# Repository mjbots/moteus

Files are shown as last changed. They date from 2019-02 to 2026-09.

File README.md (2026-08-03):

# moteus brushless servo #

This contains full designs for the moteus brushless servo actuator,
including firmware and PCBs.

**WARNING**: This is not just a software project.  It includes designs
for moderately high power electronics.  It has not yet burned down my
(or anyone's that I know of) house, but there are no guarantees.

# Specifications #

| Name | r4.11 | c1 | n1 | x1 |
|---|---|---|---|---|
| Voltage Input | 10-44V | 10-51V | 10-54V | 10-54V |
| Peak Electrical Power  | 900W @ 30V | 250W @ 28V | 1.3kW @ 36V | 1kW @ 36V |
| Mass | 14.2g | 8.9g | 14.6g | 23.8g |
| Control Rate | 15-30kHz | - | - | - |
| PWM Switching Rate | 15-60kHz | - | - | - |
| CPU | STM32G4 | - | - | - |
| Uncooled phase current | 12A | 5A | 9A | 25A |
| Cooled phase current | 32A | 14A | 26A | 62A |
| Peak phase current | 100A | 20A | 100A | 120A |
| Communications | 5Mbps CAN-FD | - | - | - |
| Dimensions | 46x53mm | 38x38x9mm  | 46x46x8mm | 56x56x10mm  |

Assembled and tested boards can be purchased at: https://mjbots.com

# Directory structure #

* hw/ - hardware (mechanical and electrical designs)
  * controller/ - PCB design for moteus-r4.11
  * c1/ - PCB design for moteus-c1
  * n1/ - PCB design for moteus-n1
  * x1/ - PCB design for moteus-x1
* fw/ - firmware for brushless controller
* lib/ - client side software
* utils/ - diagnostic tools
* tools/ - bazel build configure
* docs/ - documentation

# Documentation #

* [Quick Start](https://mjbots.github.io/moteus/quick-start)
* [All Documentation](https://mjbots.github.io/moteus/)
* [Discord](https://discord.gg/W4hUpBb)

# Misc #

 * 

# How to support moteus development #

The easiest way to support development the moteus hardware and firmware is as follows:

1) Buy things from https://mjbots.com
2) Build awesome machines!

That's it!  If for some reason you want to go above and beyond, you can sponsor mjbots through github: https://github.com/sponsors/mjbots

# License #

All files contained in this repository, unless otherwise noted, are
available under an Apache 2.0 License:
https://www.apache.org/licenses/LICENSE-2.0

# Trademark #

mjbots Robotic Systems LLC owns and protects the "mjbots" and "moteus" trademarks in many jurisdictions.

If you want to use these names in your project or product, please read the [Trademark Policy](https://mjbots.com/trademark-policy)

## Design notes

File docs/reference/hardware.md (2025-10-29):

# Hardware Specifications

## CAD and Models

| Name | 2D CAD | 3D Model |
|---|---|---|
| moteus-c1 |[2D CAD](https://github.com/mjbots/moteus/blob/0.1-20240430/hw/c1/r1.2/20240305-moteus-c1-r1_2.pdf) | [STEP](https://github.com/mjbots/moteus/blob/0.1-20240430/hw/c1/r1.2/20240305-moteus-c1-r1_2.step) |
| moteus-r4 |[2D CAD](https://github.com/mjbots/moteus/blob/main/hw/controller/r4.5/20210124-moteus-controller-r45-mechanical.pdf) | [STEP](https://github.com/mjbots/moteus/blob/main/hw/controller/r4.5/20210124-moteus-controller-r45-mechanical.step) |
| moteus-x1 | [2D CAD](https://drive.google.com/file/d/1R7wuc7vk1khD5ZvDWPy54Bx4PgHYiUCu/view) | [STEP](https://drive.google.com/file/d/19tJa4gzy0ZBWYYsaJA-Du0PgzoDWizjL/view?usp=sharing) |
| moteus-n1 | [2D CAD](https://drive.google.com/file/d/1Ic65vT8BSeTtqz6uqd8C7l68aOMy3bMz/view?usp=share_link) | [STEP](https://drive.google.com/file/d/1wxX5G6kX6M6YZGGSceiXTOUZycxRaSIE/view?usp=share_link) |

## Electrical Limits

| Name | Min Voltage | Nominal | Abs Max Voltage | Peak Output | 3V Aux |  5V Aux | 12V Aux |
|---|---|---|---|---|---|---|---|
| moteus-c1 | 10V | 24V | 51V (<= 12S) | 20A | 50mA | 100mA | N/A |
| moteus-r4 | 10V | 24V | 44V (<= 10S) | 100A | 100mA | N/A | N/A |
| moteus-x1 | 10V | 24V | 54V (<= 12S) | 120A | 100mA | 200mA | 150mA |
| moteus-n1 | 10V | 24V | 54V (<= 12S) | 100A | 100mA | 200mA | N/A |

## Power Limits

The allowable maximum power for each moteus controller depends upon
the input voltage and PWM switching frequency.  The below table gives
the maximum allowable power at `servo.pwm_rate_hz=30000`.

| Name | Peak power | | High input power |
|---|---|---|---|
| moteus-r4  | <= 30V 900W  | linear derated | >= 38V 400W |
| moteus-c1  | <= 28V 250W  | linear derated | >= 41V 150W |
| moteus-n1  | <= 36V 2000W | linear derated | >= 44V 1000W |

For other values of `servo.pwm_rate_hz`, the allowable maximum power
changes linearly with the PWM rate, so that at 15000, the maximum
power is half of that in the above table and at 60000 it is double
that.  Note however, that efficiency of the controller goes down
significantly at higher PWM rates.

The current power limit is reported in `servo_stats.max_power_W`.  The
controller will attempt to limit output phase current so as to stay
within this reported power limit in either direction, i.e. applying
power or regenerating energy.

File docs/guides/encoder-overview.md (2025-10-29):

# Encoder Overview

This section describes the various ways moteus can be configured to use encoders to sense the rotor, output, or auxiliary devices.  If you intend to only use the onboard on-axis magnetic encoder, you can skip this section.

## Introduction

moteus uses encoders to properly control a motor. Encoders provide the feedback needed to know where the motor is and how fast it's moving. Understanding which encoder(s) to use and how to configure them is one of the key decisions you need to make when designing a system, as for many applications encoder selection is the primary determinant of performance parameters like maximum stiffness, control stability and whether homing will be necessary.

Moteus uses encoders for two distinct purposes. First, it needs **commutation** feedback - the electrical relationship between the motor's stator and rotor to apply torque correctly. Second, it needs **output** feedback - the position and velocity of your output shaft to follow commanded trajectories. A single encoder can serve both purposes, or you can use separate encoders for each.

The good news is that moteus comes with an onboard AS5047P or MA600 magnetic encoder that works out of the box for many applications. This encoder mounts on-axis with the motor. For many use cases, especially those without gear reductions, this is all you need. However, if you're using hall sensors, need higher resolution, or have a gear reducer that you want to measure the output of a reducer or other auxiliary devices, you'll want to add other encoders.

In this guide, we'll cover a few common variants and leave the rest for [the detailed encoder reference](../reference/encoders.md).

## Common Configurations

Here are the most common encoder configurations you'll encounter:

**Default configuration (onboard encoder only):** The AS5047P or MA600 onboard encoder serves as both commutation and output sensor. This works well for many applications, especially those without a reducer installed or with a reducer where either the absolute position of the output is not required or a homing step is permitted.

**Adding hall sensors:** Hall effect sensors provide robust commutation feedback and are useful in high-vibration environments or when cost is a primary concern.  When used as the only encoder, the resulting system will have poor low-velocity and position tracking performance.

**Dual encoder setups:** Using one encoder for commutation (typically the onboard or hall sensors) and a separate high-resolution encoder for output position provides the best performance for precision applications.

These two options are described in separate guides below:

- [Motor with Hall Effects](hall-effects.md) - Adding hall sensors for commutation
- [Dual Encoders](dual-encoders.md) - Using separate encoders for commutation and output

Once again, for detailed information about encoder configuration parameters, see the [Detailed Encoder Reference](../reference/encoders.md).

## Next Steps

Once the encoder has been configured, then you are ready to move on to the [motor calibration procedure](calibration.md).

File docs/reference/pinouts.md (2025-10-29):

# Pinouts

## moteus-c1



## moteus-r4



## moteus-x1



## moteus-n1



## Additional Information

### CAN Termination

CAN connections should be terminated by a 120 ohm resistor at both
ends of a bus.  Some mjbots products have built in termination
resistors, such as the pi3hat.  The mjcanfd-usb-1x and fdcanusb have a
software configurable termination resistor that is by default on.
moteus controllers have no termination resistors.  For very short
runs, the system will work terminated only on one side.  However, when
runs become longer than 0.5m, you will likely need to terminate both
ends.  This can be done by crimping a 120 ohm resistor into a JST PH3
connector and connecting it to the open data connector or by
purchasing a [CAN terminator](https://mjbots.com/products/jst-ph3-can-fd-terminator).

### Recommended Mating Hardware

| Connector | Mate P/N | Terminal P/N | Pre-crimped Wire |
|---|---|---|---|
| JST PH-3  | [PHR-3](https://mjbots.com/products/phr-3)  | [SPH-002T-P0.5L](https://mjbots.com/products/jst-ph-terminal) | [10cm, 30cm, 50cm PH3](https://mjbots.com/products/jst-ph3-cable) |
| JST GH-6  | [GHR-06V-S](https://mjbots.com/products/jst-gh6-housing) | [SSHL-002T-P0.2](https://www.digikey.com/en/products/detail/jst-sales-america-inc/SSHL-002T-P0-2/807828) | [28 AWG 20cm](https://mjbots.com/products/jst-gh-wire) |
| JST GH-7  | [GHR-07V-S](https://mjbots.com/products/jst-gh7-housing) | [SSHL-002T-P0.2](https://www.digikey.com/en/products/detail/jst-sales-america-inc/SSHL-002T-P0-2/807828) | [28 AWG 20cm](https://mjbots.com/products/jst-gh-wire) |
| JST GH-8  | [GHR-08V-S](https://mjbots.com/products/jst-gh8-housing) | [SSHL-002T-P0.2](https://www.digikey.com/en/products/detail/jst-sales-america-inc/SSHL-002T-P0-2/807828) | [28 AWG 20cm](https://mjbots.com/products/jst-gh-wire) |
| JST ZH-4  | [ZHR-4](https://www.digikey.com/en/products/detail/jst-sales-america-inc/ZHR-4/608643) | [SZH-002T-P0.5](https://www.digikey.com/en/products/detail/jst-sales-america-inc/SZH-002T-P0-5/527363) | |
| JST ZH-6  | [ZHR-6](https://www.digikey.com/en/products/detail/jst-sales-america-inc/ZHR-6/527361) | [SZH-002T-P0.5](https://www.digikey.com/en/products/detail/jst-sales-america-inc/SZH-002T-P0-5/527363) | [stm32 programmer](https://mjbots.com/products/stm32-programmer) |
| AMass XT30 | [XT30U-F](https://mjbots.com/products/xt30u-f) | | |

### Recommended Low Cost Manual Crimp Tools

- **JST PH**: [TU-190-08](https://www.amazon.com/TU-190-08-Terminals-Tool-Crimping-0-08-0-5sq-mm/dp/B01M25OLZY)
- **JST ZH**: [PEBA 1020M](https://www.amazon.com/PEBA-Ratcheting-Connectors-Crimping-terminals/dp/B0D7PKLBZT)
- **JST GH**: [PEBA 1020M](https://www.amazon.com/PEBA-Ratcheting-Connectors-Crimping-terminals/dp/B0D7PKLBZT)

### moteus-r4 - Pico-SPOX 6 ENC

The ENC/AUX1 connector on moteus-r4 are intended to be populated with
a Molex Pico-SPOX 6 connector PN 0874380643, or as an alternate, TE
5-1775444-6.

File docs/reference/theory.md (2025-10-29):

# Theory of Operation

The moteus controller is intended to drive 3 phase brushless motors
using field oriented control.  It has an integrated magnetic encoder
for sensing the rotor position, 3 half-H bridges for switching power
to each of the three phases, and current sense capability on each of
the three phases.

The primary control mode, labeled as "position" mode in the rest of
this document is a two stage cascaded controller, with both running at
the switching frequency (by default 30kHz).

The outermost stage is an optional limited acceleration and velocity
trajectory planner.  Within that is an integrated position/velocity
PID controller with optional feedforward torque.  The output of that
loop is a desired torque/current for the Q phase of the FOC
controller.

The inner stage is a current mode PI controller.  Its output is the
desired voltage value for the Q phase.  Then the magnetic encoder is
used to map the D/Q phase voltage values to the 3 phases of the motor.

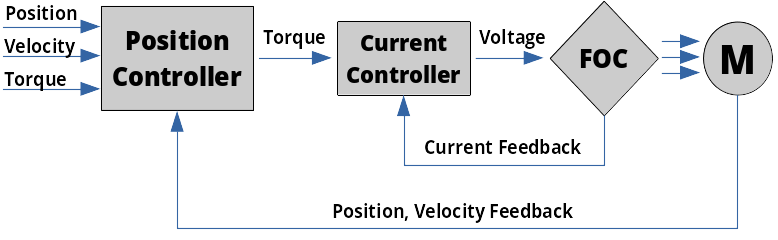
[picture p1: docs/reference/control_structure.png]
Control Structure


More precisely, the "Position Controller" implements the following
control law:

```
acceleration = trajectory_follower(command_position, command_velocity)
control_velocity = command_velocity OR control_velocity + acceleration * dt OR 0.0
control_position = command_position OR control_position + control_velocity * dt
position_error = control_position - feedback_position
velocity_error = control_velocity - feedback_velocity
position_integrator = limit(position_integrator + ki * position_error * dt, ilimit)
torque = position_integrator +
         kp * kp_scale * position_error +
         kd * kd_scale * velocity_error +
         command_torque
```

And the "Current Controller" implements the following control law:

```
current_error = command_current - feedback_current
current_integrator = limit(current_integrator + ki * current_error, ilimit)
voltage = current_integrator + kp * current_error
```

Since PID scaling for the position mode loop can be adjusted on a
cycle-by-cycle basis with the `kp_scale` and `kd_scale` terms, this
allows you to operate the controller with full
position/velocity/torque control, or velocity/torque, or just torque,
or any combination seamlessly throughout the control cycle.

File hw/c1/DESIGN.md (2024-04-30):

moteus-c1 is a small form factor controller with the flexibility of
the moteus-n1, but designed for lower power and current applications.

# r1.1 fixes #

 * U2 3.3V regulator has enable pin undriven
 * Switched U2 to part TLV70233PDBVR which is SOT23-5 and has better
   thermal properties
 * removed gate drive resistors and discharge diodes
 * moved C7 away from AUX1/AUX2 pins
 * switch can terminator (R6) to 0603 and move further away from power
   pad
 * rev silk version to r1.1
 * version divider pulled low
 * revved TVS to the 48V version, so 3V lower than before... that will
   make the rated max voltage be 51V instead of 54V
 * added unpopulated resistor and capacitor between power ground and a
   mounting hole

# TODO #

# r1.0 ERRATA #
 * C7 blocks access to the through hole pins (they barely fit, but
   could use a bit more margin)
 * can termination resistor pad is too close to power pin of XT30
 * high side FET trace to DRV is too small compared to gate drive
   trace and should be swapped around to be a pair with gate drive
 * board version divider should never be floating, needs to be
   pulled low for next rev
 * remove gate drive resistors and reverse diodes
 * 3.3V regulator should be the SOT-23 package that has better
   thermals
 * need to fully lay out what the family pullup/pulldowns are so
   that I can be sure they can all be distinguished

r1.1 MAYBE
 * possible remove all the gate drive resistors and protection diodes?
 * maybe lower max voltage to 51V and drop the TVS diode by one step

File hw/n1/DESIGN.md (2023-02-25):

moteus-n1 is intended as a higher power/voltage, more flexible, yet
smaller in footprint version of the moteus brushless controller.

# Features #

 * 51V max voltage (vs 44V for moteus)
 * More flexible aux1/aux2 connectors
   * both JST GH (aux1 is 8 pin, aux2 is 7 pin)
   * 200mA of 5V between both connectors
   * 200mA of 3V between both connectors
   * aux1 now has two pins that can be used even if onboard encoder is used
   * SPI on both connectors
   * UART on both connectors
   * ADC on both connectors
   * Sine/cosine on both connectors
   * Hardware quadrature (higher count rates)
 * RS422 transceiver and connector (consumes the two spare pins on AUX1)
 * No connectors required on bottom of board for smaller footprint
 * Optional solder pads for power in for higher current capability
 * Variants
   * optional power/CAN connectors on bottom for daisy chaining
 * CAN transceiver with 58V bus fault voltage
 * 46x46mm

# Pin Allocation #

 * PA0  - MOTOR 1       (fast ADC1/2)
 * PA1  - MOTOR 2       (fast ADC1/2)
 * PA2  - MOTOR 3       (fast ADC1)
 * PA3  - CURRENT       (fast ADC1)
 * PA4  - DEBUG_DAC
 * PA5  - AUX1_A
 * PA6  - CURRENT       (fast ADC2)
 * PA7  - AUX1_C
 * PA8  - TSENSE2       (fast ADC5)
 * PA9  - VSENSE        (fast ADC5)
 * PA10 - AUX2_A
 * PA11 - AUX2_B
 * PA12 - AUX2_I2C_PULLUP
 * PA13 - SWDIO
 * PA14 - SWCLK
 * PA15 - AUX1_D
 * PB0  - DRV8353 CS
 * PB1  - CURRENT        (fast ADC3)
 * PB2  - AS5047P CS     (ADC2)
 * PB3  - AUX1_E
 * PB4  - AUX1_B
 * PB5  - FDCAN2_RX
 * PB6  - FDCAN2_TX
 * PB7  - AUX2_C
 * PB8  - AUX1_I2C_PULLUP
 * PB9  - AUX1_E
 * PB10 - RS422_RE
 * PB11 - RS422_DE      (ADC1/2)
 * PB12 - TSENSE1      (fast ADC4)
 * PB13 - MOTOR_FAULT  (fast ADC3)
 * PB14 - AUX1_A       (fast ADC1/4)
 * PB15 - LED1         (fast ADC4)
 * PC4  - AUX2_B       (fast ADC2)
 * PC6  - LED2
 * PC10 - DRV8323 SCK
 * PC11 - DRV8323 MISO
 * PC13 - DRV8323 MOSI
 * PC14 - MOTOR_ENABLE
 * PC15 - MOTOR_HIZ
 * PF0 - AUX2_A
 * PF1 - AUX2_D

# Pins Required #

     * LEDs - 2
     * as5047 CS - 1
     * drv8353 CS - 1
     * 2x temp sense - 2
     * debug uart - 2
     * swd - 2
     * DAC debug?
     * voltage sense - 1
     * aux ADC - 2
     * primary aux - 1
     * CAN - 2
     * current sense - 3
       * needs to be "fast" ADC channels
     * aux fixed conn - 2
     * primary fixed conn - 4 (SPI shared with as5047)
     * drv8353 SPI - 3
     * gate PWM - 3

# Connectors #

## Aux 1 ##

 * notional pins (8  pins)
  * 5V
  * 3.3v
  * A: SPI1_SCK  / ADC1 / TIM2_CH1                             - PA5 / PB14
  * B: SPI1_MISO /      / TIM3_CH1 /          / USART2_RX / 5V - PB4
  * C: SPI1_MOSI / ADC2 / TIM3_CH2                             - PA7
  * D:           /      / TIM2_CH1 / I2C1_SCL / USART2_RX / 5V - PA15
  * E: SPI1_SCK  /      / TIM2_CH2 / I2C1_SDA / USART2_TX / 5V - PB3 / PB9
  * gnd

## Aux 2 ##

 * 3V and 5V power
 * I2C
 * quadrature
 * index
 * uart
 * SPI
 * PA14/PA15 have I2C1 and USART2 and TIM8_CH1/2
 * PB8/PB9 have I2C1 and USART3 and TIM4_CH3/4
 * TIM1/2 options: PA0/1/2/3/5/6/7/12/15
                   PB2/3/4/5/6/7/8/9/14/15
 * notional pins (7 pins)
   * 5V
   * 3V
   * A: SPI2 SCK  /           /          / ADC2 /           - PF1
   * B: SPI2 MISO / USART1_RX / I2C2_SDA / ADC1             - PA10 / PF0
   * C: SPI2 MOSI / USART1_TX / I2C2_SCL / ADC2 / TIM4_CH1  - PA11 / PC4
   * D:             USART1_RX /                 / TIM4_CH2  - PB7
   * gnd

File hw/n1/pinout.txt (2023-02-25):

PA0 TIM2_CH1 TIM5_CH1 ADC1_IN1 ADC2_IN1 ANALOG
PA1 TIM2_CH2 TIM5_CH2 ADC1_IN1 ADC2_IN1 ANALOG
PA2 5V USART2_TX LPUART1_TX ADC1_IN3 ANALOG
PA3 USART2_RX LPUART1_RX ADC1_IN4 ANALOG
PA4 TIM3_CH2 ADC2_IN17 ANALOG
PA5 TIM2_CH1 SPI1_SCK ADC2_IN13 ANALOG
PA6 TIM3_CH1 SPI1_MISO ADC2_IN3 ANALOG
PA7 TIM3_CH2 SPI1_MOSI ADC2_IN4 ANALOG
PA8 5V I2C3_SCL I2C2_SDA TIM1_CH1 ADC5_IN1 ANALOG
PA9 5V I2C2_SCL TIM1_CH2 USART1_TX ADC5_IN2 ANALOG
PA10 5V SPI2_MISO USART1_RX ANALOG
PA11 5V SPI2_MOSI TIM4_CH1
PA12 5V TIM4_CH2
PA15 5V TIM2_CH1 TIM8_CH1 I2C1_SCL USART2_RX
PB0 ADC3_IN12 ADC1_IN15 ANALOG
PB1 ADC3_IN1 ADC1_IN12 ANALOG
PB2 TIM5_CH1 TIM20_CH1 ADC2_IN12 ANALOG
PB3 5V TIM2_CH2 SPI1_SCK SPI3_SCK USART2_TX
PB4 5V TIM3_CH1 SPI1_MISO SPI3_MISO USART2_RX
PB5 5V TIM3_CH2 I2C1_SMBA SPI1_MOSI SPI3_MOSI I2C3_SDA
PB6 5V TIM4_CH1 TIM8_CH1 USART1_TX
PB7 5V TIM4_CH2 I2C4_SDA I2C1_SDA USART1_RX LPTIM1_IN2
PB8 5V I2C_SCL USART3_RX TIM8_CH2
PB9 5V I2C1_SDA USART3_TX
PB10 USART3_TX LPUART1_RX OPAMP3_VINM OPAMP4_VINM ANALOG
PB11 USART3_RX LPUART1_TX ADC1_IN14 ADC2_IN14 OPAMP4_VINP ANALOG
PB12 ADC4_IN13 ADC1_IN11 OPAMP6_VINP ANALOG
PB13 SPI2_SCK ADC3_IN5 OPAMP3_VINP OPAMP4_VINP OPAMP5_VINP ANALOG
PB14 TIM15_CH1 SPI2_MISO ADC4_IN4 ADC1_IN5 OPAMP2_VINP OPAMP5_VINP ANALOG
PB15 SPI2_MOSI ADC4_IN5 ADC2_IN15 OPAMP5_VINM ANALOG
PC4 5V I2C2_SCL USART1_TX ADC2_IN5 ANALOG
PC5 USART1_RX ADC2_IN11 ANALOG
PC6 5V TIM3_CH1 TIM8_CH1 I2C4_SCL
PC10 5V UART4_TX SPI3_SCK USART3_TX
PC11 5V UART4_RX SPI3_MISO USART3_RX I2C3_SDA
PC13 5V TIM5_CH2 UART5_TX SPI3_MOSI
PF0 5V I2C2_SDA ADC1_IN10 ANALOG
PF1 5V SPI2_SCK ADC2_IN10 ANALOG

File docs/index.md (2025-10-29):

# moteus Brushless Servo Documentation

Welcome to the documentation site for the moteus brushless motor controller.

## What is moteus?

moteus controllers are high-performance modular brushless motor controllers with integrated on-axis magnetic encoders, designed for robotics applications. They feature:

- **Field Oriented Control (FOC)** for 3-phase brushless motors
- **Integrated magnetic encoder** for precise position sensing
- **High-speed CAN-FD communication** at 5Mbps
- **Multiple control modes**: Position, velocity, and torque control with acceleration and velocity limited trajectories
- **Fast control loops** running at 15-30kHz

## Hardware Variants

| Name | Voltage Input | Peak Power | Mass  | Dimensions |
|---|---|---|---|---|
| r4.11  | 10-44V | 900W @ 30V | 14.2g | 46x53mm |
| c1 | 10-51V | 250W @ 28V | 8.9g  | 38x38x9mm |
| n1 | 10-54V | 2kW @ 36V | 14.6g | 46x46x8mm |
| x1 | 10-54V | 1.3kW @ 36V | 23.8g | 56x56x10mm |

Assembled and tested boards can be purchased at [mjbots.com](https://mjbots.com)

## Documentation

- [Quick Start](quick-start.md)
- [Using Moteus](guides/mechanical-setup.md)
- [Integration](integration/python.md)
- [Troubleshooting](troubleshooting/calibration.md)
- [Reference](reference/pinouts.md)

## Community & Support

- [Discord Community](https://discord.gg/W4hUpBb)
- [GitHub Repository](https://github.com/mjbots/moteus)
- [Purchase Hardware](https://mjbots.com)

## License

All files in this repository are available under the [Apache 2.0 License](https://www.apache.org/licenses/LICENSE-2.0).

!!! note "Trademark Notice"
    mjbots Robotic Systems LLC owns and protects the "mjbots" and "moteus" trademarks. Please read the [Trademark Policy](https://mjbots.com/trademark-policy) if you want to use these names in your project.

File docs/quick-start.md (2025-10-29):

# Quick Start Guide

New to moteus?  Work through these sections in order.  The first set
is if you have a bare board, the second is if you are starting from a
developer kit.

## Setup Overview for Bare Boards

If you have a bare moteus board and a motor, these steps are for you.

1. **[Mechanical Setup](guides/mechanical-setup.md)** - Mount the encoder magnet and controller
2. **[Electrical Setup](guides/electrical-setup.md)** - Connect phase wires and power
3. **[Software Installation](guides/software-installation.md)** - Install and run tview
4. **[Configuration](guides/configuration.md)** - Set essential parameters
5. **[Encoder Overview](guides/encoder-overview.md)** - Understand encoder options (if using external encoders)
6. **[Calibration](guides/calibration.md)** - Calibrate the controller for your motor
7. **[PID Tuning](guides/pid-tuning.md)** - Tune the position control constants
8. **[Control Modes](guides/control-modes.md)** - Learn how to control the motor

## Developer Kit Users

If you're starting from a developer kit, the motor is already mounted,
configured, calibrated and tuned. Your job is easier, yay!  Just follow these steps:

1. **[Software Installation](guides/software-installation.md)** - Install tview
2. **[Control Modes](guides/control-modes.md)** - Start controlling your motor

## Need Help?

- **[Troubleshooting](troubleshooting/calibration.md)** - Common issues and solutions
- **[Discord Community](https://discord.gg/W4hUpBb)** - Get help from the community
- **[GitHub Issues](https://github.com/mjbots/moteus/issues)** - Report bugs or request features
- **[info@mjbots.com](mailto:info@mjbots.com)** - Email support

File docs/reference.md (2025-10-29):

# Reference Documentation

This page has been reorganized. Please use the navigation menu or the links below to find the content you're looking for.

## Quick Links

### Theory and Operation

**[Theory of Operation](https://mjbots.github.io/moteus/reference/theory/)** - Controller architecture and control laws

**[Usage Modes / Control Modes](https://mjbots.github.io/moteus/guides/control-modes/)** - Position, velocity, and torque control modes

### Configuration

**[Initial Parameters / Configuration](https://mjbots.github.io/moteus/guides/configuration/)** - Getting started with configuration

**[Encoder Configuration](https://mjbots.github.io/moteus/guides/encoder-overview/)** - Encoder setup and configuration

**[Auxiliary Port](https://mjbots.github.io/moteus/reference/encoders/#auxiliary-port)** - Auxiliary connector configuration and pinouts

**[AUX1/ENC Pins](https://mjbots.github.io/moteus/reference/encoders/#r411-pins-aux1enc)** - r4.11 AUX1/ENC connector pinout

**[AUX2/ABS Pins](https://mjbots.github.io/moteus/reference/encoders/#r411-pins-aux2abs)** - r4.11 AUX2/ABS connector pinout

**[AUX GPIO Output Control](https://mjbots.github.io/moteus/protocol/diagnostic/#aux1-out-set-gpio-output-values)** - Setting GPIO outputs via diagnostic commands

**[AUX UART Mode](https://mjbots.github.io/moteus/reference/encoders/#uart)** - Configuring UART on auxiliary ports

**[Pin Capabilities](https://mjbots.github.io/moteus/reference/encoders/#io-pin-capabilities)** - Available pin modes and configurations

### Configuration Parameters

**[id.id](https://mjbots.github.io/moteus/reference/configuration/#idid)** - Device ID configuration

**[servo.default_timeout_s](https://mjbots.github.io/moteus/reference/configuration/#servodefault_timeout_s)** - Command timeout configuration

**[servo.flux_brake_margin_voltage](https://mjbots.github.io/moteus/reference/configuration/#servoflux_brake_margin_voltage)** - Flux braking voltage threshold

**[servo.max_power_W](https://mjbots.github.io/moteus/reference/configuration/#servomax_power_w)** - Maximum power limit

**[servo.pid_position](https://mjbots.github.io/moteus/reference/configuration/#servopid_position)** - Position PID controller parameters

**[servopos.position_min](https://mjbots.github.io/moteus/reference/configuration/#servoposposition_min)** - Minimum position limit

**[motor_position.output.offset/sign](https://mjbots.github.io/moteus/reference/configuration/#motor_positionoutputoffsetsign)** - Output encoder offset and sign

**[motor_position.rotor_to_output_ratio](https://mjbots.github.io/moteus/reference/configuration/#motor_positionrotor_to_output_ratio)** - Gear reduction ratio

**[Configuration Commands](https://mjbots.github.io/moteus/protocol/diagnostic/#conf-configuration)** - Reading and writing configuration via console

### Register Reference

**[0x000 - Mode](https://mjbots.github.io/moteus/protocol/registers/#0x000-mode)** - Operational mode register

**[0x00f - Fault Code](https://mjbots.github.io/moteus/protocol/registers/#0x00f-fault-code)** - Fault status register

**[0x014/0x15/0x16 - Voltage Phase A/B/C](https://mjbots.github.io/moteus/protocol/registers/#0x014-0x15-0x16-voltage-phase-a-b-c)** - Phase voltage control registers

**[0x020 - Position Command](https://mjbots.github.io/moteus/protocol/registers/#0x020-position-command)** - Position setpoint register

**[0x021 - Velocity Command](https://mjbots.github.io/moteus/protocol/registers/#0x021-velocity-command)** - Velocity setpoint register

**[0x023 - Kp Scale](https://mjbots.github.io/moteus/protocol/registers/#0x023-kp-scale)** - Proportional gain scaling

**[0x025 - Maximum Torque](https://mjbots.github.io/moteus/protocol/registers/#0x025-maximum-torque)** - Torque limit register

**[0x028 - Velocity Limit](https://mjbots.github.io/moteus/protocol/registers/#0x028-velocity-limit)** - Trajectory velocity limit

**[0x058 - Encoder Validity](https://mjbots.github.io/moteus/protocol/registers/#0x058-encoder-validity)** - Encoder status bitfield

**[0x05c - Aux1 GPIO Command](https://mjbots.github.io/moteus/protocol/registers/#0x05c-aux1-gpio-command)** - GPIO output control register

**[0x070 - Millisecond Counter](https://mjbots.github.io/moteus/protocol/registers/#0x070-millisecond-counter)** - System timestamp register

**[0x131 - Set Output Exact](https://mjbots.github.io/moteus/protocol/registers/#0x131-set-output-exact)** - Force absolute position register

**[0x150-0x153 - UUID](https://mjbots.github.io/moteus/protocol/registers/#0x150-0x153-uuid)** - Device UUID registers

**[0x154-0x157 - UUID Mask](https://mjbots.github.io/moteus/protocol/registers/#0x154-0x157-uuid-mask)** - UUID filtering registers

**[Register Mappings](https://mjbots.github.io/moteus/protocol/registers/#mappings)** - Data type encodings and scaling

**[Register List](https://mjbots.github.io/moteus/protocol/registers/#registers)** - Complete register documentation

### CAN Protocol

**[CAN Format](https://mjbots.github.io/moteus/protocol/can/#can-format)** - CAN-FD frame structure

**[Write Registers](https://mjbots.github.io/moteus/protocol/can/#write-registers)** - Register write subframe format

**[CAN Protocol Example](https://mjbots.github.io/moteus/protocol/can/#example)** - Sample CAN frame breakdown

**[Sending Multiple Commands](https://mjbots.github.io/moteus/reference/client-tools/#sending-multiple-commands-at-once)** - Batching commands in tview

**[Communicating with Specific Device](https://mjbots.github.io/moteus/reference/client-tools/#communicating-with-a-specific-device)** - Targeting devices by ID

**[CAN Bit Timings](https://mjbots.github.io/moteus/platforms/socketcan/#bit-timings)** - socketcan bitrate configuration

**[Clock-Specific Bit Timings](https://mjbots.github.io/moteus/platforms/socketcan/#bit-timings)** - 40MHz and 80MHz configurations

### Diagnostic Commands

**[Diagnostic Protocol](https://mjbots.github.io/moteus/protocol/diagnostic/)** - Console command reference

**[d pwm](https://mjbots.github.io/moteus/protocol/diagnostic/#d-pwm)** - Raw PWM control command

**[d nearest](https://mjbots.github.io/moteus/protocol/diagnostic/#d-nearest)** - Set output nearest command

**[d cfg-set-output](https://mjbots.github.io/moteus/protocol/diagnostic/#d-cfg-set-output)** - Configure output encoder

### Hardware Reference

**[Pinouts](https://mjbots.github.io/moteus/reference/pinouts/)** - Connector pinouts for all board variants

**[Debug Port (JST ZH-6)](https://mjbots.github.io/moteus/reference/pinouts/)** - SWD debug connector

**[n1/c1 AUX2 (JST GH-7)](https://mjbots.github.io/moteus/reference/pinouts/)** - n1 and c1 auxiliary port connector

**[r4 ABS (JST ZH-4)](https://mjbots.github.io/moteus/reference/pinouts/)** - r4 absolute encoder connector

**[r4 ENC (Pico-SPOX-6)](https://mjbots.github.io/moteus/reference/pinouts/)** - r4 incremental encoder connector

**[Hardware Specifications](https://mjbots.github.io/moteus/reference/hardware/)** - Electrical ratings and mechanical information

**[Application Limits](https://mjbots.github.io/moteus/reference/limits/)** - Position, velocity, and performance constraints

### Calibration and Tuning

**[Calibration](https://mjbots.github.io/moteus/guides/calibration/)** - Motor and encoder calibration procedures

**[PID Tuning](https://mjbots.github.io/moteus/guides/pid-tuning/)** - Controller tuning methodology

### Firmware and Tools

**[Flashing and Building Firmware](https://mjbots.github.io/moteus/reference/firmware/)** - Firmware compilation and installation

**[tview Usage](https://mjbots.github.io/moteus/reference/client-tools/#tview-usage)** - Command-line tool documentation

### Deployment

**[Deployment Considerations](https://mjbots.github.io/moteus/guides/electrical-setup/)** - Production design guidelines and safety considerations

### Additional Topics

**[Hall Effect Sensors](https://mjbots.github.io/moteus/reference/encoders/#hall-sensor)** - Using motors with hall effect sensors or configuring hall sensor pins

**[Position Mode](https://mjbots.github.io/moteus/guides/control-modes/#understanding-position-mode)** - Position control details

**[Torque Control](https://mjbots.github.io/moteus/guides/control-modes/#torque-control)** - Direct torque control mode

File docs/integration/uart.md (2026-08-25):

# UART

In systems where CAN-FD is not available, moteus can be commanded and monitored over a TTL level UART connection.

## Default configuration

By default, moteus controllers with a sufficiently new firmware version have the following pins configured for that purpose.

* [moteus-r4](../reference/pinouts.md#moteus-r4): aux2 - JST ZH-4
  * A - Host TX / moteus RX
  * B - Host RX / moteus TX
* [moteus-c1](../reference/pinouts.md#moteus-c1): aux2 - JST GH-7
  * C - Host RX / moteus TX
  * D - Host TX / moteus RX
* [moteus-n1](../reference/pinouts.md#moteus-n1)/[moteus-x1](../reference/pinouts.md#moteus-x1): aux1 - JST GH-8
  * D - Host TX / moteus RX
  * E - Host RX / moteus TX

Serial parameters:

* Baudrate: 921600
* Data bits: 8
* Stop bits: 1
* Parity: None

To use these pins for any other purpose, the appropriate [`aux[12].uart.mode`](../reference/configuration.md#aux12uartmode) must be set to "Disabled (0)".

## Protocol

In this mode, moteus acts as if it were a fdcanusb device on the UART.  The moteus python, C++, and rust libraries can be used directly if the operating system device name for the UART is given instead of the fdcanusb.  The only difference is that moteus permits checksums on command lines and always emits checksums on response lines.  Once any command has been sent with a checksum, all further commands require a checksum.

The checksum uses the following format:

```
data line *XX
```

Where the '*' character is followed by two hexadecimal digits.  Those are the CRC-8 using polynomial 0x97.  Sample calculation routines are:

=== "Python"

    ```python
    _CRC8_TABLE = [
        0x00, 0x97, 0xb9, 0x2e, 0xe5, 0x72, 0x5c, 0xcb,
        0x5d, 0xca, 0xe4, 0x73, 0xb8, 0x2f, 0x01, 0x96,
    ]

    def compute_crc8(data: bytes) -> int:
        """Compute CRC-8 using polynomial 0x97, nybble-at-a-time."""
        crc = 0
        for b in data:
            crc = _CRC8_TABLE[((crc >> 4) ^ (b >> 4)) & 0x0f] ^ ((crc << 4) & 0xff)
            crc = _CRC8_TABLE[((crc >> 4) ^ (b & 0x0f)) & 0x0f] ^ ((crc << 4) & 0xff)
        return crc

    ```

=== "C++"
    ```cpp
    static constexpr uint8_t kCrc8Table[16] = {
        0x00, 0x97, 0xb9, 0x2e, 0xe5, 0x72, 0x5c, 0xcb,
        0x5d, 0xca, 0xe4, 0x73, 0xb8, 0x2f, 0x01, 0x96,
    };

    static uint8_t ComputeCrc8(const char* data, size_t len) {
      uint8_t crc = 0;
      for (size_t i = 0; i < len; i++) {
        const uint8_t b = static_cast<uint8_t>(data[i]);
        crc = kCrc8Table[((crc >> 4) ^ (b >> 4)) & 0x0f] ^ (crc << 4);
        crc = kCrc8Table[((crc >> 4) ^ (b & 0x0f)) & 0x0f] ^ (crc << 4);
      }
      return crc;
    }
    ```

## Usage with moteus tools and library

To use moteus_tool or tview with a UART connection, you must specify the path to the UART device on the command line:

```bash
python -m moteus_gui.tview --fdcanusb /dev/ttyUSB0
```

or:

```bash
python -m moteus.moteus_tool --fdcanusb /dev/ttyUSB0 -t 1 --info
```

When integrating with the python library, you must manually construct a transport:

```python
fdcanusb = moteus.Fdcanusb('/dev/ttyUSB0')
c = moteus.Controller(id=1, transport=fdcanusb)
```

or for C++

```cpp
using mjbots;
moteus::Controller controller([]() {
  moteus::Controller::Options options;
  options.transport = std::make_shared<moteus::Fdcanusb>("/dev/ttyUSB0");
  return options;
}());
```

or for rust

```rust
let transport = moteus::Fdcanusb::open("/dev/ttyUSB0")?;
let mut controller = moteus::BlockingController::with_transport(1, transport);
```

For embedded (no_std) rust hosts, the `moteus-protocol` crate provides an allocation-free codec for this protocol in its `fdcanusb` module.

For usage with Arduino, see that [platform integration reference](../platforms/arduino.md).

## Caveats

### Reconfiguring

If a UART is the only means of communication, it can be challenging to configure the UART pins to a different port or a different baud rate. As with nearly all moteus configurable values, configuration changes take place *immediately*.  Thus it is recommended to first configure the new port location.  If the new port is on a lower number aux port, as soon as it is configured it will become the only means of control.  Then the host can be switched to that port in order to save configuration and reconfigure the original UART pins.

Similarly, if an error is present on a given aux port configuration, then that will disable UART control along with all other functions on that aux port, even if the error is associated with a different pin on that aux port.  It may be necessary to power cycle the device or use CAN-FD to restore control.

**Note**: If the baud rate is changed from the default 921600 and moteus client side tools are used, the `--fdcanusb-baudrate` option can be used to specify the correct value.  See the [Client Tools Reference](../reference/client-tools.md#configuring-the-communications-transport)

### Addressing

moteus emulates a subset of the fdcanusb protocol, including any configured ID and CAN prefix.  Thus if you change `id.id` or `can.prefix`, you will need to use the correct CAN IDs and prefixes in further communication with the device.

### Non-bus topology

When using UART control, only a single moteus device can be connected to a single host UART port.

### Flashing

It is not possible to flash new firmware using the UART transport.  Only CAN-FD and the SWD port with a st-link are supported.

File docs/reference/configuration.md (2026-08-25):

# Configuration Parameters

This section describes the configurable values which are most likely
to be modified for end-user applications.  Changes to all values take
effect *immediately*.  This may mean, that for instance, it is wise to
stop control loops before drastically changing control parameters.  Or
maybe not, it depends upon your goals.

## `id.id`

The servo ID presented on the CAN bus.  After this is modified, you need to immediately adjust which servo ID you communicate with in order to continue communication or save the parameters.

## `can.prefix`

A 13 bit integer used as the upper 13 bits for the ID of all CAN
communication.  As with `id.id` this takes effect immediately, so
after changing it, communication must be restarted with the correct
prefix in order to do things like save the configuration.

## `servopos.position_min`

The minimum allowed control position value, measured in rotations.  If
NaN, then no limit is applied.

## `servopos.position_max`

The maximum allowed control position value, measured in rotations.  If
NaN, then no limit is applied.

## `servo.pid_position`

These configure the position mode PID controller.

* `kp/ki/kd` - PID gains with units of:
  * kp - Nm per rotation
  * ki - Nm/s per rotation
  * kd - Nm per rotation/s
* `iratelimit` - The maximum rate at which the integral term can
   wind up, in N*m/s.  <0 means "no limit"
* `ilimit` - The total maximum I term, in Nm
* `max_desired_rate` - If non-zero, the commanded position is
  limited to change at this rate in Hz.

Note, these values are in physical units.  Thus a `kp` value of 1,
means that for 1 revolution of error at the output, 1 Nm of corrective
torque will be applied.  Similarly, with a `kd` value of 1, 1
revolution per second of error will result in 1 Nm of corrective
torque.  Doubly note that these values are measured at the output,
thus *after* any scaling in position, velocity, and torque implied by
`motor_position.rotor_to_output_ratio`.

## `servo.pid_dq_hz`

The bandwidth of the current control loop in Hz.  The PI gains for the
current controller are computed automatically from this bandwidth and
the calibrated motor resistance and inductance.  It is normally set
during calibration by the `--cal-bw-hz` option to `moteus_tool`.

## `servo.max_current_desired_rate`

The maximum rate at which the desired current can change, in A/s.  0
means unlimited.

## `servo.default_velocity_limit` / `servo.default_accel_limit`

Limits to be placed on trajectories generated within moteus.  If
either is `nan`, then that limit is unset.  The limits may also be
overriden individually on a per command basis.  The semantics of the
limits are as follows:

- *Neither set (both nan)* In this case, position and velocity
  commands take immediate effect.  The control position will be
  initialized to the command position, and the control velocity will
  be set to the command velocity.  The control position will advance
  at the given velocity indefinitely, or until the command stop
  position is reached.

- *Either set*: If x_c is the command position, v_c is the command
  velocity, and t is the time from receipt of the command, the
  semantics can be described as: "match the trajectory defined by x =
  x_c + v_c * t".

  If the acceleration limit is set, the above is effected by
  commanding accelerations of either [-accel_limit, 0, accel_limit].
  If an acceleration limit is not set, then the velocity will change
  instantaneously.

  If the velocity limit is set, then the intermediate velocities will
  obey "-velocity_limit < velocity < +velocity_limit".  If it is not
  set, then the velocities may grow to arbitrary magnitude.

NOTE: This is limited internally to be no more than
`servo.max_velocity`.

## `servo.inertia_feedforward`

When set to non-zero, and acceleration limits are currently in effect,
this will apply a feedforward torque equal to the current acceleration
multiplied by this configurable value.  This can be used to improve
response transients for short movements, where the acceleration period
is not long enough for the normal position PID to track well.

In an ideal world, you would set this to the moment of inertia of your
system in measured in kg * m^2.

## `servo.voltage_mode_control`

When set to non-zero, the current control loop is not closed, and all
current commands in amperes are instead treated as voltage mode
commands in volts related by the calibrated phase resistance.  For
high winding resistance motors, the default current sense resistors
are too small for accurate current sensing, resulting in significant
cogging torque and current sense noise.  If replacing the current
sense resistors is not an option, this flag can be used to achieve
smooth control.  The downside is that the actual torque will no longer
follow the applied torque accurately at speed, or in the face of
external disturbances.

When set, the `servo.pid_dq_hz` configuration value no longer affects
anything.

## `servo.fixed_voltage_mode`

If non-zero, then no feedback based control of either position or
current is done.  Instead, a fixed voltage is applied to the phase
terminals based on the current commanded position and the configured
number of motor poles.  In this mode, the encoder and current sense
resistors are not used at all for control.

This is a similar control mode to inexpensive brushless gimbal
controllers, and relies on burning a fixed amount of power in the
motor windings continuously.

When this mode is active, the reported position and velocity will be 0
when the drive is disabled, and exactly equal to the control position
when it is enabled.

Various derating limits are inoperative in this mode:
 * torque derating for temperature
 * torque derating when outside position bounds
 * the maximum current limit
 * the commanded maximum torque

A fault will still be triggered for over-temperature.

## `servo.fixed_voltage_control_V`

In the fixed voltage control mode, the voltage to apply to the output.

## `servo.max_position_slip`

When finite, this enforces a limit on the difference between the
control position and the current measured position measured in
revolutions.  It can be used to prevent "catching up" when the
controller is used in velocity mode.

## `servo.max_velocity_slip`

When finite, this enforces a limit on the difference between the
control velocity and the current measured velocity, measured i Hz.  It
can be used to ensure that acceleration limits are obeyed in velocity
mode when external torques exceed the maximum.  If used, typically
`servo.max_position_slip` must be relatively small to avoid
instability.

## `servo.max_voltage`

If the input voltage reaches this value, a fault is triggered and all
torque is stopped.

## `servo.max_power_W`

If set, set the allowable maximum power to the lower of this and the
factory board power profile.

## `servo.override_board_max_power`

If true, then `servo.max_power_W` is used as the power limit even if
it is larger than the factory board power profile.

## `servo.pwm_rate_hz`

The PWM rate to use, defaulting to 30000.  Allowable values are
between 15000 and 60000.  Lower values increase efficiency, but limit
peak power and reduce the maximum speed and control bandwidth.

## `servo.temperature_margin`

Torque begins to be limited when the temperature is within this many
degrees Celsius of `servo.fault_temperature`.

## `servo.fault_temperature`

If the temperature reaches this value, a fault is triggered and all
torque is stopped.

## `servo.enable_motor_temperature`

If true, then the motor temperature will be sensed via the TEMP pads
on the board.

## `servo.motor_temperature_margin`

Torque begins to be limited when the motor temperature is within this
many degrees Celsius of `servo.motor_fault_temperature`.

## `servo.motor_fault_temperature`

If the motor temperature reaches this value, a fault is triggered and
all torque is stopped.

## `servo.fault_position_error`

If finite, a fault is triggered when the absolute position control
error exceeds this value.  The position control error is the
difference between the commanded and measured position in revolutions.
If set to `nan` (the default), no fault is triggered.

## `servo.fault_velocity_error`

If finite, a fault is triggered when the absolute velocity control
error exceeds this value.  The velocity control error is the
difference between the commanded and measured velocity in revolutions
per second.  If set to `nan` (the default), no fault is triggered.

## `servo.max_regen_power_W`

When regenerating, moteus will dissipate energy in the windings in the
motor in order to limit the maximum regenerative power to the input bus
below this amount.

`nan` disables the feature, in which case only flux braking will result in energy being dissipated in the windings.

`0` means allow no regenerative power to the input bus.

WARNING: The amount of power that can be dissipated in the windings is
subject to the current limit of the board, along with the supply
voltage and phase winding resistance.  Once moteus reaches the maximum
amount of power that can be applied to the phase windings, further
power will be directed to the input bus regardless of the value of
this setting.

## `servo.flux_brake_margin_voltage`

Selects the flux braking point relative to the currently configured `servo.max_voltage`.  `flux braking point = max_voltage - flux_brake_margin_voltage`.

When the input voltage is above the braking point, the controller
causes the motor to act as a "virtual resistor" with resistance
`servo.flux_brake_resistance_ohm`.  All extra energy is dumped into
the D phase of the motor.  This can be used to handle excess
regenerative energy if the input DC link is incapable of accepting
sufficient energy.

## `servo.max_current_A`

Phase current will never be used more than this value.  It can be
decreased to limit the total power used by the controller.  Increasing
beyond the factory configured value can result in hardware damage.

## `servo.max_velocity`

Output power will be limited if the velocity exceeds this threshold.

## `servo.max_velocity_derate`

Once velocity reaches the max_velocity plus this value, allowed output
power is reduced to 0.

## `servo.rotation_*`

These values configure a higher order torque model for a motor.

* `servo.rotation_current_cutoff_A` if the phase current is less than
  this value, then the linear relationship implied by `motor.Kv`
  is used.

Once above that cutoff, the following formula is used to determine
torque from phase current:

```
torque = cutoff * tc + torque_scale * log2(1 + (I - cutoff) * current_scale)
```

Where `tc` is the torque constant derived from `motor.Kv`.

This model is not automatically calibrated, and needs to be determined
and configured manually.

## `servo.default_timeout_s`

When sending position mode commands over CAN, there is an optional
watchdog timeout.  If commands are not received at a certain rate,
then the controller will latch into the "position timeout" state,
requiring a stop command to resume operation.  This configuration
value controls the length of time that the controller will wait after
receiving a command before entering this state.  If set to `nan` then
the controller will never enter this timeout state.

It may be overidden on a per-command basis with the 0x027 register or
the `t` optional flag of the `d pos` command for the diagnostic
interface.

## `servo.timeout_max_torque_Nm`

When in the "position timeout" mode the controller acts to damp the
output.  This parameter controls the maximum torque available for such
damping.

## `servo.timeout_mode`

Selects what behavior will take place in the position timeout mode.
The allowable values are a subset of the top level modes.

* 0 - "stopped" - the driver is disengaged
* 10 - "decelerate to 0 velocity and hold position"
* 12 - "zero velocity"
* 15 - "brake"

For mode 10, `servo.default_velocity_limit` and
`servo.default_accel_limit` are used to control the deceleration
profile to zero speed.  The default PID gains are used.  The only
limit on torque when in this timeout mode is `servo.max_current_A`.

## `servo.motor_thermistor_ohm`

The resistance of any attached motor NTC thermistor as measured at 25C
in ohms.

## `servo.fw.enable`

If true, then operation above the base speed will be permitted.  The controller will use negative D axis current to lower the effective Kv value, resulting in increased power dissipation when above the base speed.

## `servo.fw.max_current_ratio`

When operating in field weakening, the D axis current magnitude is limited to no more than this multiplied by `servo.max_current_A`.

## `aux[12].pins.X.mode`

Selects what functionality will be used on the given pin.

* 0 - NC - Not connected (or used for onboard SPI)
* 1 - SPI - Used for one of CLK, MISO, or MOSI
* 2 - SPI CS - Used for SPI CS
* 3 - UART
* 4 - Software quadrature
* 5 - Hardware quadrature
* 6 - Hall
* 7 - Index
* 8 - Sine
* 9 - Cosine
* 10 - Step (not implemented)
* 11 - Dir (not implemented)
* 12 - RC PWM (not implemented)
* 13 - I2C
* 14 - Digital input
* 15 - Digital output
* 16 - Analog input
* 17 - PWM output

## `aux[12].pins.X.pull`

Configures optional pullup or pulldown on each pin.  Not all pullup
options will be used with every mode.  Additionally, the 2 aux2 pins
on moteus 4.5/8/11 have hard-installed 2k ohm pullups regardless of
these settings.

* 0 - no pullup or pulldown
* 1 - pull up
* 2 - pull down
* 3 - open drain (not implemented)

## `aux[12].i2c.i2c_hz`

The frequency to operate the I2C bus at.  Between 50000 and 400000.

## `aux[12].i2c.i2c_mode`

What I2C mode to use.

## `aux[12].i2c.pullup`

Configure I2C specific 2.2k pullup resistors on the I2C specific pins.
If set, an error is reported for the aux port if configurable I2C
pullups are not available on this auxiliary port for this board.

## `aux[12].i2c.devices.X.type`

What I2C device to expect.

* 0 - disabled
* 1 - AS5048
* 2 - AS5600

## `aux[12].i2c.devices.X.address`

The I2C address to use.

## `aux[12].i2c.devices.X.poll_rate_us`

How often in microseconds to poll the device for more data.  Must be
no less than 100.

## `aux[12].spi.mode`

The type of SPI device.

* 0 - The onboard AS5047P (CPR == 16384). Only valid for aux1.  If
  selected, the CLK, MOSI, and MISO lines must be either NC or
  selected as SPI.
* 1 - Disabled.
* 2 - AS5047P (CPR == 16384)
* 3 - iC-PZ
* 4 - MA732 (CPR == 65536)
* 5 - MA600 (CPR == 65536)
* 8 - AMT22 (CPR == 16384)
* 9 - RLS Orbis (CPR == 16384)

NOTE: iC-PZ devices require significant configuration and calibration
before use.  Diagnostic mode commands are provided for low level
access.

## `aux[12].spi.rate_hz`

The frequency to operate the SPI bus at.  The default is 12000000.

## `aux[12].uart.mode`

The type of UART device.

* 0 - Disabled
* 1 - RLS AksIM-2
* 2 - Tunnel
* 3 - Per-control cycle debug information (undocumented)
* 4 - CUI AMT21x series RS422
* 5 - fdcanusb serial protocol, see [UART](../integration/uart.md)
* 6 - "board default" - resolves to the board and port specific default on boot

When the tunnel mode is selected, data may be sent or received using
the CAN diagnostic protocol.  For aux1, use diagnostic channel 2.  For
aux2, use diagnostic channel 3.

The default value of this varies across auxiliary port and moteus board.

* moteus-r4: aux1/Disabled(0), aux2/fdcanusb(5)
* moteus-c1: aux1/Disabled(0), aux2/fdcanusb(5)
* moteus-n1: aux1/fdcanusb(5), aux2/Disabled(0)
* moteus-x1: aux1/fdcanusb(5), aux2/Disabled(0)

If a particular auxiliary port does not have an RX and TX pin
appropriately configured, the `uart.mode` must be set to Disabled(0).

## `aux[12].uart.baud_rate`

The baud rate to use for the UART.

## `aux[12].uart.poll_rate_us`

For encoder modes, the interval at which to poll the encoder for new
position information.

## `aux[12].uart.cui_amt21_address`

Select the CUI AMT21 address to communicate with.  The default is 0x54
(84 decimal), which is the default address CUI AMT21 encoders are
configured with.

## `aux[12].quadrature.enabled`

True/non-zero if quadrature input should be read from this port.

## `aux[12].quadrature.cpr`

The number of counts per revolution of the quadrature input.  If used
as a source, then this CPR must match the one configured in the
source.

## `aux[12].hall.enabled`

True/non-zero if hall effect sensors should be read from this port.

## `aux[12].hall.polarity`

A bitmask to XOR with the 3 hall phases.

## `aux[12].index.enabled`

True/non-zero if an index input be read from this port.

## `aux[12].sine_cosine.enabled`

True/non-zero if a sine/cosine input should be read from this port.

## `aux[12].sine_cosine.common`

The common mode voltage to use for the sine cosine.  The sampling is
done with 12 bits, so 2048 would be exactly 0.5 * 3.3V.  However, it
is best to calibrate this with actual readings as observed over the
diagnostic protocol for optimal performance.

## `aux[12].bissc.enabled`

True/non-zero if a BiSS-C sensor should be attached to this port.
BiSS-C encoders require two pins, one of which is suitable both as a
UART-TX pin and PWM pin.

## `aux[12].bissc.rate_hz`

The bitrate used for BiSS-C communication.  1,000,000 (1Mbit) is the
maximum supported rate.

## `aux[12].bissc.data_bits`

The number of data bits reported by the BiSS-C encoder.

## `aux[12].bissc.crc_bits`

The number of CRC bits reported by the BiSS-C encoder.

## `aux[12].bissc.poll_rate_us`

The minimum period with which to poll the BiSS-C encoder.

## `aux[12].i2c_startup_delay_ms`

A delay in milliseconds after power-on (or upon reconfiguring), before
I2C devices associated with this auxiliary port are first used.

## `aux[12].pwm_period_us`

The period in microseconds to be used for PWM outputs on this
auxiliary port.

## `aux[12].rs422`

Enable the RS422 transceiver.  This is only valid for 'aux1', and
requires that pin D and E (`aux1.pins.3` and `aux1.pins.4`) be
used for UART or BiSS-C.

## `motor_position.sources.X.aux_number`

1 for an aux1 device, or 2 for an aux2 device.

## `motor_position.sources.X.type`

One of:

* 0 - disabled
* 1 - SPI
* 2 - UART
* 3 - Quadrature
* 4 - Hall
* 5 - Index
* 6 - Sine/Cosine
* 7 - I2C
* 8 - Sensorless (not implemented)

Note: The "Index" source type is only allowed for an output referenced
encoder, and can be used as an alternate way to enter the "output"
homed state.

## `motor_position.sources.X.i2c_device`

If `type` was "7/I2C", this is a 0 based index specifying *which* I2C
device on that port should be used.

## `motor_position.sources.X.incremental_index`

If the specified auxiliary port has an incremental encoder, like a
quadrature encoder, this can be set to either 1 or 2 in order to use
an "index" pin to reference the data to a given position.  It will
allow the source to provide theta readings for commutation.

## `motor_position.sources.X.cpr`

The CPR of the given input.  In some cases this is automatically set,
but in most it will need to be manually entered.

## `motor_position.sources.X.offset/sign`

An integer offset and inversion to apply.  The resulting value is:
`(raw + offset) * sign / cpr`.

## `motor_position.sources.X.reference`

* 0 - this source is relative to the rotor
* 1 - this source is relative to the output

## `motor_position.sources.X.pll_filter_hz`

Selects the 3dB cutoff frequency of a low-pass filter used on this
source.  It should typically be less than 10X the update rate of the
input and if used as the commutation or output sensor, should be
higher than the mechanical bandwidth of the plant.  Within that range,
it can be tuned for audible noise versus performance.

If set to 0, then no filter is applied.  In that case, sensors which
do not natively measure velocity will produce no velocity readings
(most of them).

## `motor_position.commutation_source`

A 0-based index into the source list that selects the source to use
for commutation.  This means it should have an accurate measure of the
relationship between the rotor and stator.

It is not recommended to use quadrature sources for commutation as
they can lose counts and require additional application level homing
support at each power-on.

## `motor_position.output.source`

A 0-based index into the source list that selects the source to use
for the output position.  The position and velocity from this source
will be used for control in "position" mode.

## `motor_position.output.offset/sign`

The offset is a floating point value measured in output revolutions.
Combined with the sign of -1/1, they can be used to position the 0
point of the output and control its direction of rotation.

## `motor_position.output.reference_source`

If non-negative, this is a 0-based index into the source list.  The
selected source is used at power on to disambiguate the output
position for multi-turn scenarios or when a reducer is configured.

## `motor_position.rotor_to_output_ratio`

The number of times the output turns for each revolution of the rotor.
For gear reducers (almost all configurations), this will be less than
one.  For example, a 4x gear reduction would be entered as 0.25.

## `motor_position.rotor_to_output_override`

If you *REALLY* know what you are doing, and want to configure a
non-reducing ratio, this can be set to true/non-zero.  Otherwise, a
ratio of greater than 1.0 will cause a fault.  This should only be
used if the system has a gearbox which is not a reducer, but speeds up
the output.

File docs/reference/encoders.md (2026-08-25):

# Encoder Configuration Reference

This page contains detailed technical reference for advanced encoder configuration.

## Overview

moteus includes an onboard on-axis magnetic encoder and supports a
number of options for using external encoders.  To understand how to
use them, we first need to know the two things that moteus needs
encoders for:

- *Commutation*: moteus needs to know the electrical relationship
  between the stator and the rotor in order to apply torque.
- *Output*: moteus needs to know the position and velocity of the
  output shaft in order to follow commanded trajectories.

By default, the onboard magnetic encoder (AS5047P) is assumed to sense
the rotor.  It is also used as the source for position and velocity of
the output constrained by a configurable reduction ratio.

Configuration is performed in 3 stages: first is the auxiliary port
configuration, second is encoder source configuration, and finally is
the output configuration.

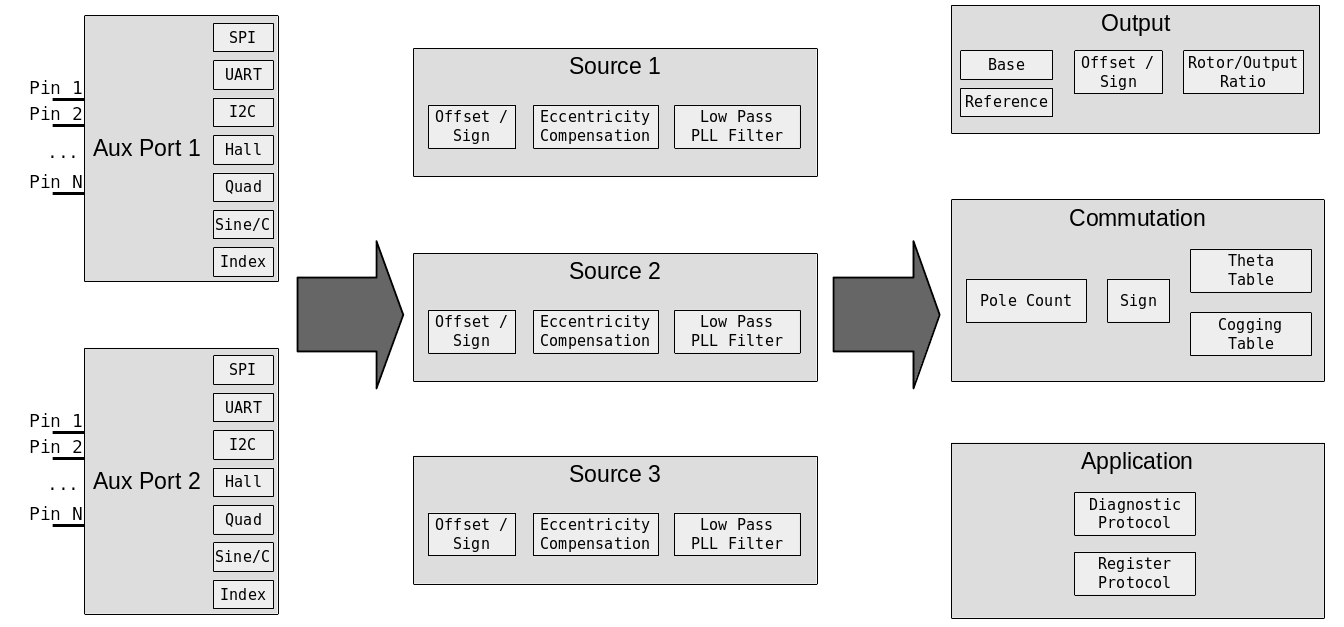
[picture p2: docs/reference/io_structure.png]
IO Structure


## Supported Encoders

The following encoders are currently supported by moteus:

| Name | Interface Method | Performance | Mounting | Price |
|---|---|---|---|---|
| Onboard AS5047P | SPI (integrated) | +++ | on-axis | Included  |
| AS5047x | SPI | +++ | on-axis | $ |
| AS5048B | I2C | ++ | on-axis | $ |
| AS5600 | I2C | + | on-axis | $ |
| AksIM-2 | RS422 w/ 5V | +++++ | off-axis | $$$ |
| CUI AMT21x | RS422 w/ 5V | ++++ | shaft | $$ |
| CUI AMT22x | SPI w/ 5V | ++++ | shaft | $$ |
| MA600 | SPI | ++++ | on/off-axis | $ |
| MA732 | SPI | +++ | on/off-axis | $ |
| BiSS-C | RS422 w/ 5V | ++++ | on/off-axis | $$$ |
| iC-PZ | SPI w/ 5V | +++++ | off-axis | $$$ |
| RLS Orbis | SPI w/ 5V | ++++ | off-axis | $$ |
| Quadrature | Quadrature | variable | x | x |
| Sine/Cosine | Sine/Cosine | + | x | x |
| Hall effect | Hall effect | | x | $ |

## Auxiliary Port

There are two auxiliary ports on moteus, each with pins that can be
used for various functions.

They can provide power to external devices in addition to I/O pins:

| | 3V | 5V | 12V |
|---|---|---|---|
| moteus-r4.5 | 50mA | N/A | N/A |
| moteus-r4.8-4.11| 100mA | N/A | N/A |
| moteus-c1 | 50mA | 100mA | N/A |
| moteus-n1 | 100mA | 200mA | N/A |
| moteus-x1 | 100mA | 200mA | 150mA |

## I/O Pin capabilities

- **Con**: The pin number on the connector
- **Aux**: The number used to configure the pin in `aux?.pins.X`
- **SPI**: Serial peripheral interface support
- **ADC/Sin/Cos**: Supports analog input, and sine/cosine input
- **I2C**: Inter-integrated circuit protocol
- **HW Quad/PWM**: Supports "hardware" quadrature input and PWM output

### r4.11 Pins (AUX1/ENC)

| moteus r4.5/8/11 | Con | Aux | SPI  | ADC/Sin/Cos | I2C | HW Quad/PWM | UART | 5VT |
|---|-----|-----|---|---|-----|---|---|-----|
| 3.3V  (3) | 1 | | | | | | | |
| C | 2 | 0 | X | | | | | X |
| GND (G) | 3 | | | | | | | |
| K | 4 | 1 | CLK  | X | | | | |
| I | 5 | 2 | MISO | X | | | | |
| O | 6 | 3 | MOSI | X | | | | |

### r4.11 Pins (AUX2/ABS)

| moteus r4.5/8/11 | Con | Aux | SPI  | ADC/Sin/Cos | I2C | HW Quad/PWM | UART | 5VT |
|---|-----|-----|---|---|-----|---|---|-----|
| 3.3V (3) | 1 | | | | | | | |
| | 2 | 0 | | | SCL | | RX | X |
| | 3 | 1 | | | SDA | | TX | X |
| GND (G) | 4 | | | | | | | |
| DBG 1 | | 2 | | | | | | X |
| DBG 2 | | 3 | | | | | | X |

Note: For moteus r4.5/8/11, DBG 1/2 are not present on the ABS connector, but are exposed pads on the circuit board.

### c1 Pins

The moteus-c1 has limited AUX1 port availability. Only pins D and E from AUX1 are exposed on an unpopulated 0.05" through-hole land pattern. I2C pullups are not available on moteus-c1 for aux1.

| moteus c1  | Con | AUX | SPI  | ADC/Sin/Cos | I2C | HW Quad/PWM | UART | 5VT |
|---|-----|-----|---|---|-----|---|---|-----|
| D | | 3 | | | SCL | 2.1 | RX | X |
| E | | 4 | | | SDA | 2.2 | TX | X |

### n1/x1 Pins (AUX1/ENC)

| moteus n1/x1  | Con | AUX | SPI  | ADC/Sin/Cos | I2C | HW Quad/PWM | UART | 5VT |
|---|-----|-----|---|---|-----|---|---|-----|
| 5V (5) | 1 | | | | | | | |
| 3.3V (3) | 2 | | | | | | | |
| A | 3 | 0 | CLK  | X | | | | |
| B * | 4 | 1 | MISO | | | 3.1 | RX | |
| C | 5 | 2 | MOSI | X | | 3.2 | | |
| D | 6 | 3 | | | SCL | 2.1 | RX | X |
| E | 7 | 4 | | | SDA | 2.2 | TX | X |
| GND (G) | 8 | | | | | | | |

Note: For moteus n1, the B pin software configured pullup cannot be used effectively. Thus the B pin is unsuitable for open-drain inputs like hall effect sensors unless external pullups are provided.

Note: The moteus n1 and x1 have a hardware RS422 transceiver connected to aux1's pins D and E which can be enabled through configuration. RS485 devices like the CUI AMT21x can be used if the RS422 pin Y is connected to A and RS422 pin Z is connected to B.

### c1/n1/x1 Pins (AUX2/ABS)

| moteus n1/x1  | Con | AUX | SPI  | ADC/Sin/Cos | I2C | HW Quad/PWM | UART | 5VT |
|---|-----|-----|---|---|-----|---|---|-----|
| 5V (5) | 1 | | | | | | | |
| 3.3V (3) | 2 | | | | | | | |
| A | 3 | 0 | CLK  | X | | | | X |
| B | 4 | 1 | MISO | X | SDA | | RX | X |
| C | 5 | 2 | MOSI | X | SCL | 4.1 | TX | X |
| D | 6 | 3 | | | | 4.2 | RX | X |
| GND (G) | 7 | | | | | | | |

## Pin Capabilities

The following capabilities can be used.  Some are supported on any
pins, others only on select pins.

### Software Quadrature Input

Pins: any

The software quadrature feature uses GPIO pins to read incremental
quadrature encoders.  It is capable of counting at 200,000 counts per
second without error, but incurs processor overhead that increases
with count rate.  Higher overhead means the latency to respond to CAN
messages increases.

### Hall sensor

Pins: any

3 hall sensor inputs are required.  For many hall sensors, the pullup
must be configured for the auxiliary port pin in question.

When using hall effect sensors as the commutation source, calibration
with moteus_tool requires the `--cal-hall` option be passed.

### Index

Pins: any

This is a single pin that is high when the encoder is in a known
location.  It can be fed from the "I" signal of an ABI output, or a
dedicated homing sensor.

### GPIO Input

Pins: any

Any pin may be designated as a GPIO input.  Its value may be read over
the diagnostic or register protocols.

### I2C Master

Pins: select

Between 1 and 3 I2C devices may be periodically polled at rates up to
200Hz.  The associated pins on moteus r4.5/8/11 have permanently
configured 2kohm pullup resistors.

### SPI Master

Pins: select

A variety of SPI based peripherals are supported.  This mode is also
used for the onboard encoder, which when enabled, claims the CLK,
MOSI, and MISO pins on auxiliary port 1.

### Hardware Quadrature Input

Pins: select

Hardware quadrature pins use microcontroller peripherals to process
quadrature input at any speed with no processor overhead.

### Sine/cosine

Pins: select

Analog sine/cosine inputs are supported with a configurable common
mode voltage.

### Analog input

Pins: select

Arbitary analog inputs can be read either over the diagnostic or
register protocol.

### UART

Pins: select

A variety of asynchronous serial encoders and debugging facilities are
supported.

The moteus-n1 and moteus-x1 additionally have a hardware RS422
transceiver connected to aux1's pins D and E which can be enabled
through configuration.  RS485 devices like the CUI AMT21x can be used
if the RS422 pin Y is connected to A and RS422 pin Z is connected to
B.

### BiSS-C

Pins: select

To configure BiSS-C encoders, two pins are required.  One is used for
transmission and must be on a pin that supports both a UART TX
capability and hardware quadrature input.  The other pin is
unrestricted and will be used for receipt.  On moteus-n1 and
moteus-x1, aux1 D/E are connected to the onboard RS422 transceiver and
can be used to directly interface to BiSS-C encoders.

## Pin Configuration

Auxiliary port configuration is achieved in two steps.

First, the `aux[12].pins.X.mode` value is set to the proper capability
for each pin.  `aux[12].pins.X.pull` can be used to configure an
optional pullup or pulldown for some modes.

Second, the corresponding capabilities must be configured in one of
the capability specific sections of `aux[12]`.  For instance, for each
auxiliary port, the SPI configuration in `aux[12].spi` has a `mode` to
select what the slave device is and a `rate_hz` to define the
frequency of the SPI peripheral.  Any capability section that is not
in use must be disabled.  By default, different moteus controllers
have the UART configured to serial control mode on some auxiliary
ports which may need to be disabled.

For I2C ports, up to 3 different slave devices may be configured, in
each of `aux[12].i2c.devices.[012]`.

The diagnostic values in `aux[12]` can be used to monitor for errors
from mis-configuration or mis-operation.

## Encoder Configuration

In addition to configuring pins, most encoders require an additional
level of configuration at the port level.  Most of these configurable
options are documented in the [configuration
reference](configuration.md).

## Source Configuration

Once the auxiliary ports have been configured, next encoder sources
should be configured in `motor_position.sources`.  Up to 3 sources may
be configured, with the available types roughly corresponding to the
categories available from the auxiliary ports.  Typically, source 0 is
used for the sensor that is used for commutation.

For each source `motor_position.sources.[012].aux_number` should be
either "1" or "2", to select which auxiliary port the sensor should be
read from.  `motor_position.sources.[012].type` selects the type of
sensor.  For I2C based sources,
`motor_position.sources.[012].i2c_device` selects *which* I2C device
on that auxiliary port is used.

For sources that are incremental only, like quadrature, a source level
index may be configured in
`motor_position.sources.[012].incremental_index`.  This should be used
if the incremental source is needed to provide position for
commutation.

Each source can be marked as measuring the rotor or the output in
`motor_position.sources.[012].reference`.

Each source has configuration that determines how to map the raw value
provided by the device into a rotary angle.  `cpr` is the number of
counts per revolution, `offset` provides an integral count offset, and
`sign` can be used to invert the reading.  The final reading is
`(raw + offset) * sign / cpr`.

Finally, each source has a configurable low pass filter, with cutoff
frequency set by `motor_position.sources.[012].pll_filter_hz`.  It may
be set to 0 to disable the filter.  If disabled no velocity will be
interpolated on sensors that do not provide it natively.

## Output Configuration

The third major stage controls how the sources are used by the motor
controller.  Some source selections may be left at -1, which disables
that feature.

`motor_position.commutation_source` selects which source is used to
provide rotor position for commutation purposes.  It is typically left
at source 0 and is required.  Note, quadrature sources are not
recommended for commutation as they can lose counts and require
additional application level homing support on each power-on.

`motor_position.output.source` selects which source is used to provide
output position and velocity and is required.

`motor_position.output.offset` and `motor_position.output.sign` are
used to transform the output position to achieve a given zero point
and rotational direction.

`motor_position.output.reference_source` optionally configures a
source that is used solely to disambiguate the output position at
startup.  It could be a low-rate I2C based sensor for instance, or an
index source configured from a homing switch.

Finally, `motor_position.rotor_to_output_ratio` defines the number of
turns of the output for one turn of the rotor.  This is used to map
the readings from sensors that are defined relative to one into the
other.  For gear reducers (almost all configurations), this will be
less than one.  For example, a 4x gear reduction would be entered as
0.25.

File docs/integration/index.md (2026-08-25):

# Integration

Integrate moteus with your software and hardware.

- [Python Client](python.md) - Python client library
- [C++ Client](cpp.md) - C++ client library
- [Rust Client](rust.md) - Rust client library
- [Raw CAN-FD](can-fd.md) - Direct CAN-FD protocol access
- [UART](uart.md) - Logic level UART access

## Host Platforms

- [Raspberry Pi](../platforms/raspberry-pi.md) - Using moteus with Raspberry Pi
- [Nvidia Jetson](../platforms/jetson.md) - Using moteus with Jetson boards
- [socketcan](../platforms/socketcan.md) - Linux SocketCAN setup
- [Arduino](../platforms/arduino.md) - Arduino integration

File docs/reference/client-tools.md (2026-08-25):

# Client Tools

## tview usage

tview can monitor and control 1 or more devices simultaneously.  It can be started with:

```
python3 -m moteus_gui.tview --target 1[,2,3]...
```

When running, the configuration for each can be modified in the left hand tab, and live telemetry values can be displayed or plotted from the right hand tab.  diagnostic mode commands may be issued in the bottom terminal window.

### Communicating with a specific device

If more than one device is available, commands can be sent to a specific device by prefixing the command with `ID>`.  For instance, to send a stop command to ID #2, you can do:

```
2>d stop
```

The 'A' character can be used to send to all devices simultaneously.

```
A>d stop
```

### Sending multiple commands at once

The `&&` token may be used to separate individual commands, which will be issued back to back.  For instance:

```
1>d stop && 2>d stop
```

Will send the command to both devices.

### Delays

A delay may be inserted into a sequence of commands by entering an integer number of milliseconds prefixed by the colon (':') character.  For instance:

```
d pos nan 0.5 1 s0.5 && :1000 && d stop
```

Will command a position mode, wait 1s, then command a stop.

### Waiting for a trajectory to complete

A sequence of commands can be paused until a controller has finished
its trajectory using the `?` character.

```
d pos 0 0 nan a2 && ? && d pos 1 0 nan a2
```

Will move to position 0, wait until that motion is complete, then move
to position 1, all with an acceleration limit of 2.

Specific devices can be queried by following the question mark with an
ID number.

```
2>d pos 0 0 nan a2 && 1>d pos 10 0 0 nan a2 && ?2 && 2>d stop
```

## Calibration

Assuming your controller has firmware installed already, you can
calibrate the controller using the following procedure.

```
python3 -m moteus.moteus_tool --target 1 --calibrate
```

WARNING: Any attached motor must be able to spin freely.  It will be
spun in both directions and at high speed.

After calibrating for an entirely new type of motor, you may need to
adjust PID gains before the motor will perform acceptably, and/or
configure `motor_position.rotor_to_output_ratio`.

## Setting the "zero offset"

The moteus controller can locate positions within one revolution after being power cycled, and will start with the reported position being between -0.5 and 0.5.  The physical zero position can be set using the following command:

```
python3 -m moteus.moteus_tool --target 1 --zero-offset
```

## Configuring the communications transport

`moteus_tool` and `tview` can be configured to communicate with a
moteus controller through a variety of transports.  By default, it
will attempt to autodetect either a fdcanusb or socketcan interface.

To force usage of a particular fdcanusb or a logic level UART, you can
use:

```
python3 -m moteus.moteus_tool --fdcanusb /path/to/fdcanusb
```

To force a particular python-can method, you can use:

```
python3 -m moteus.moteus_tool --can-iface socketcan --can-chan can0
```

where `--can-iface` specifies the "interface" for python-can and
`--can-chan` specifies the "channel".

Note, these are in addition to any other `moteus_tool` or `tview`
options that may be desired.

If a non-default baud rate is used with a logic level UART, then the baudrate can be specified with `--fdcanusb-baudrate`, like:

```
python3 -m moteus.moteus_tool --fdcanusb /dev/ttyUSB0 --fdcanusb-baudrate 115200
```

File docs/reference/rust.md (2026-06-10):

# Rust API Reference

The moteus Rust library is split into two crates. Full auto-generated documentation is available on docs.rs.

- [**moteus** on docs.rs](https://docs.rs/moteus/) — High-level controller API
- [**moteus-protocol** on docs.rs](https://docs.rs/moteus-protocol/) — Low-level protocol types (`no_std` compatible)

This page provides a curated summary of the key types and their roles.

## moteus crate

### Controllers

[`BlockingController`](https://docs.rs/moteus/latest/moteus/struct.BlockingController.html)
:   Synchronous controller with auto-discovered transport.
    Simplest API for single-threaded use.
    Provides `set_position()`, `set_stop()` and other blocking methods that send a command and return a `QueryResult`.

[`AsyncController`](https://docs.rs/moteus/latest/moteus/struct.AsyncController.html)
:   Async controller for use with `async`/`.await`.
    Supports both wrapped-blocking and true async (tokio feature) transports.
    Same method set as `BlockingController`, but all methods return futures.

[`Controller`](https://docs.rs/moteus/latest/moteus/struct.Controller.html)
:   Low-level frame builder.
    Produces `Command` values without any transport — use for custom transports or embedded systems.
    Provides `make_position_command()`, `make_stop()`, `parse_query()`, etc.

### Commands and Results

[`Command`](https://docs.rs/moteus/latest/moteus/struct.Command.html)
:   A routed moteus message combining destination/source/prefix with serialized multiplex protocol data.
    Produced by `Controller::make_*()` methods.
    Convert to a wire-level `CanFdFrame` via `into_frame()`.

[`command::PositionCommand`](https://docs.rs/moteus/latest/moteus/command/struct.PositionCommand.html)
:   Position mode parameters: position, velocity, feedforward torque, torque limits, PID scales, acceleration/velocity limits, and more.
    Uses a builder pattern — chain `.position()`, `.velocity()`, `.maximum_torque()`, etc.

[`command::StopCommand`](https://docs.rs/moteus/latest/moteus/command/struct.StopCommand.html)
:   Stop command that clears faults and sets the controller to stopped mode.

[`command::CurrentCommand`](https://docs.rs/moteus/latest/moteus/command/struct.CurrentCommand.html)
:   Direct current (d/q axis) control command.

[`command::VFOCCommand`](https://docs.rs/moteus/latest/moteus/command/struct.VFOCCommand.html)
:   Voltage FOC (field-oriented control) command.

[`command::StayWithinCommand`](https://docs.rs/moteus/latest/moteus/command/struct.StayWithinCommand.html)
:   Stay-within bounds command — the controller maintains position within specified limits.

[`command::ZeroVelocityCommand`](https://docs.rs/moteus/latest/moteus/command/struct.ZeroVelocityCommand.html)
:   Zero velocity mode command — the controller actively holds zero velocity.

[`query::QueryFormat`](https://docs.rs/moteus/latest/moteus/query/struct.QueryFormat.html)
:   Specifies which registers to query and at what resolution.
    Customize to request additional telemetry fields beyond the defaults (mode, position, velocity, torque).

[`query::QueryResult`](https://docs.rs/moteus/latest/moteus/query/struct.QueryResult.html)
:   Parsed response containing mode, position, velocity, torque, voltage, temperature, fault code, and other telemetry fields.

### Transport Layer

[`Transport`](https://docs.rs/moteus/latest/moteus/struct.Transport.html)
:   Manages communication channels to moteus controllers.
    Provides `cycle()` (batch send/receive), `write()` (fire-and-forget), `read()` (receive unsolicited), and `flush_read()`, matching the Python API.

[`TransportOptions`](https://docs.rs/moteus/latest/moteus/struct.TransportOptions.html)
:   Configuration for transport auto-discovery.
    Set preferred interfaces, timeouts, and other options.

[`TransportOps`](https://docs.rs/moteus/latest/moteus/trait.TransportOps.html)
:   Trait for blocking transport implementations.
    Implement this to create custom transport backends.

[`AsyncTransport`](https://docs.rs/moteus/latest/moteus/struct.AsyncTransport.html) *(requires `tokio` feature)*
:   Async transport wrapper for true non-blocking I/O with tokio.

[`AsyncTransportOptions`](https://docs.rs/moteus/latest/moteus/struct.AsyncTransportOptions.html) *(requires `tokio` feature)*
:   Configuration for async transport creation.

[`AsyncTransportOps`](https://docs.rs/moteus/latest/moteus/trait.AsyncTransportOps.html) *(requires `tokio` feature)*
:   Trait for async transport implementations.

### Transport Backends

[`transport::fdcanusb::Fdcanusb`](https://docs.rs/moteus/latest/moteus/transport/fdcanusb/struct.Fdcanusb.html)
:   fdcanusb serial (CDC) transport.
    Auto-detected when an fdcanusb device is connected via USB.

[`transport::socketcan::SocketCan`](https://docs.rs/moteus/latest/moteus/transport/socketcan/struct.SocketCan.html)
:   Linux SocketCAN transport.
    Uses the kernel CAN interface (e.g., `can0`).

[`transport::async_fdcanusb::AsyncFdcanusb`](https://docs.rs/moteus/latest/moteus/transport/async_fdcanusb/struct.AsyncFdcanusb.html) *(requires `tokio` feature)*
:   Async fdcanusb transport using tokio-serial.

[`transport::async_socketcan::AsyncSocketCan`](https://docs.rs/moteus/latest/moteus/transport/async_socketcan/struct.AsyncSocketCan.html) *(requires `tokio` feature)*
:   Async SocketCAN transport using tokio.

### Diagnostics and Utilities

[`DiagnosticStream`](https://docs.rs/moteus/latest/moteus/struct.DiagnosticStream.html)
:   Blocking diagnostic protocol stream for reading and writing configuration values, firmware info, and other diagnostic commands.

[`AsyncDiagnosticStream`](https://docs.rs/moteus/latest/moteus/struct.AsyncDiagnosticStream.html) *(requires `tokio` feature)*
:   Async variant of the diagnostic stream.

[`move_to()`](https://docs.rs/moteus/latest/moteus/move_to/fn.move_to.html)
:   Free function for coordinated multi-servo moves.
    Moves multiple servos to target positions simultaneously, waiting for all to arrive.

[`async_move_to()`](https://docs.rs/moteus/latest/moteus/move_to/fn.async_move_to.html) *(requires `tokio` feature)*
:   Async variant of coordinated multi-servo moves.

[`Error`](https://docs.rs/moteus/latest/moteus/enum.Error.html)
:   Error enum with variants: `Io`, `Timeout`, `NoResponse`, `Fault`, `InvalidResponse`, `NotConnected`, `DeviceNotFound`, `Protocol`.
    Implements `std::error::Error` and `From<std::io::Error>`.

### Factory and Discovery

[`get_singleton_transport()`](https://docs.rs/moteus/latest/moteus/fn.get_singleton_transport.html)
:   Returns a shared global transport instance.
    Creates the transport on first call using auto-discovery.

[`create_default_transport()`](https://docs.rs/moteus/latest/moteus/fn.create_default_transport.html)
:   Creates a new transport with default auto-discovery settings.

[`register()`](https://docs.rs/moteus/latest/moteus/fn.register.html)
:   Register a custom transport factory for auto-discovery.
    Allows third-party transport backends to participate in automatic transport selection.

[`DeviceAddress`](https://docs.rs/moteus/latest/moteus/struct.DeviceAddress.html)
:   Address a device by CAN ID, UUID, or both.
    UUID-based addressing enables automatic ID resolution on the bus.

## moteus-protocol crate

This crate is `no_std` compatible (with optional `std` feature) and provides the wire protocol types:

[`CanFdFrame`](https://docs.rs/moteus-protocol/latest/moteus_protocol/struct.CanFdFrame.html)
:   Raw CAN-FD frame with `arbitration_id`, `data`, `size`, `brs`, and `fdcan` fields.
    Contains no routing information — routing is handled by `Command` in the moteus crate.

[`Register`](https://docs.rs/moteus-protocol/latest/moteus_protocol/enum.Register.html)
:   Enum of all moteus register addresses (mode, position, velocity, torque, voltage, temperature, fault, encoder registers, etc.).

[`Resolution`](https://docs.rs/moteus-protocol/latest/moteus_protocol/enum.Resolution.html)
:   Register value resolution: `Ignore`, `Int8`, `Int16`, `Int32`, `Float`.
    Controls the precision and wire size of register values.

[`Mode`](https://docs.rs/moteus-protocol/latest/moteus_protocol/enum.Mode.html)
:   Controller operating mode enum: `Stopped`, `Fault`, `Position`, `ZeroVelocity`, `StayWithin`, `Current`, etc.

[`HomeState`](https://docs.rs/moteus-protocol/latest/moteus_protocol/enum.HomeState.html)
:   Homing state enum: `Relative`, `Rotor`, `Output`.

[`Scaling`](https://docs.rs/moteus-protocol/latest/moteus_protocol/struct.Scaling.html)
:   Register scaling helpers for encoding/decoding fixed-point values to/from wire format.

[`command::*`](https://docs.rs/moteus-protocol/latest/moteus_protocol/command/index.html)
:   Command structs and serialization for all command types.
    Each command type has a corresponding format struct that controls which fields are sent and at what resolution.

[`query::*`](https://docs.rs/moteus-protocol/latest/moteus_protocol/query/index.html)
:   Query format and result types with deserialization.
    `QueryFormat` controls which registers are requested; `QueryResult` holds the parsed response.

[`calculate_arbitration_id()`](https://docs.rs/moteus-protocol/latest/moteus_protocol/fn.calculate_arbitration_id.html)
:   Compute a CAN arbitration ID from source, destination, prefix, and reply flag.

[`parse_arbitration_id()`](https://docs.rs/moteus-protocol/latest/moteus_protocol/fn.parse_arbitration_id.html)
:   Parse source, destination, prefix, and reply flag from a CAN arbitration ID.

## Feature Flags

`tokio`
:   Enables true async transports using tokio.
    Adds `AsyncFdcanusb`, `AsyncSocketCan`, `AsyncTransport`, `AsyncDiagnosticStream`, and `async_move_to()`.

`clap`
:   Enables `add_transport_args()` for CLI argument parsing with clap.

## Integration Guide

For usage examples and tutorials, see the [Rust Client integration guide](../integration/rust.md).

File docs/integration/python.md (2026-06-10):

# Python Client Library

moteus provides a python library that can be used to command and control moteus controllers using a supported CAN-FD adapter.

## Installation

To install, just use:

```
pip install moteus
```

Or add to your `requirements.txt` file, or via whatever mechanism your project uses.

## Basic Usage

There are two basic approaches to using the python library.  The first is the easiest, although does not provide optimal bus utilization if that is a design requirement.

First, construct one or more controller instances:

```python
import asyncio
import moteus

async def main():
    c1 = moteus.Controller(id=1)
    c2 = moteus.Controller(id=2)
    # ...

if __name__ == '__main__':
    asyncio.run(main())
```

Then, at regular intervals, send commands to each of the devices using the `set_` variant of each API.

```python
while True:
  c1_result = await c1.set_position(
      position=math.nan, velocity=1.0, accel_limit=0.5, query=True)
  c2_result = await c2.set_position(
      position=math.nan, velocity=0.5, accel_limit=0.25, query=True)

  c1_position = c1_result.values[moteus.Register.POSITION]
  c2_position = c2_result.values[moteus.Register.POSITION]

  print(c1_position, c2_position)

  await asyncio.sleep(0.01)
```

## `.cycle` based usage

If bus utilization or a high update rate is desired, an alternate API can be used to maximize performance.  In this API, the commands are constructed in advance using `make_` variants of commands, then submitted to the library in a group.

```python
import argparse
import asyncio
import moteus

async def main():
    parser = argparse.ArgumentParser()
    moteus.make_transport_args(parser)
    args = parser.parse_args()

    transport = moteus.get_singleton_transport(args)
    c1 = moteus.Controller(id=1, transport=transport)
    c2 = moteus.Controller(id=2, transport=transport)
    # ...

    while True:
        results = await transport.cycle([
           c1.make_position(position=math.nan, query=True)
           c2.make_position(position=math.nan, query=True),
           ])

        # Print the ID and position of all received responses.
        print(", ".join(
            f"{x.source} " +
            f"{x.values[moteus.Register.POSITION]}"
            for x in results))

        await asyncio.sleep(0.01)

if __name__ == '__main__':
    asyncio.run(main())
```

## Querying alternate registers

By default, only a limited set of registers are queried.  The full set of available registers can be found in the [register reference documentation](../protocol/registers.md).  The easiest way to query additional registers is to pass an alternate `QueryResolution` structure to the `Controller` constructor.

```python
qr = moteus.QueryResolution()
qr.power = moteus.F32
c = moteus.Controller(id=1, query_resolution=qr)
```

If the register you want is not available in the `QueryResolution` structure, it can be requested using the `_extra` method:

```python
qr = moteus.QueryResolution()
qr._extra = {
    moteus.Register.ENCODER_1_POSITION: moteus.F32,
    moteus.Register.ENCODER_1_VELOCITY: moteus.F32,
}
c = moteus.Controller(id=1, query_resolution=qr)
```

## API Reference

- [Python API Reference](../reference/python.md)

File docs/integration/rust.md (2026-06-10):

# Rust Client Library

moteus provides a Rust client library for commanding and controlling moteus controllers using a supported CAN-FD adapter. The library consists of two crates:

- **`moteus`** — High-level controller API with transport management
- **`moteus-protocol`** — Low-level `no_std` protocol encoding/decoding

## Installation

Add the moteus crate to your project:

```
cargo add moteus
```

Or add it directly to your `Cargo.toml`:

```toml
[dependencies]
moteus = "0.5"
```

For async support with tokio, enable the `tokio` feature:

```toml
[dependencies]
moteus = { version = "0.5", features = ["tokio"] }
```

For CLI argument parsing support, enable the `clap` feature:

```toml
[dependencies]
moteus = { version = "0.5", features = ["clap"] }
```

## Basic Usage — BlockingController

The simplest way to use moteus is with `BlockingController`, which provides synchronous, blocking communication:

```rust
use std::thread;
use std::time::Duration;
use moteus::{BlockingController, command::PositionCommand};

fn main() -> Result<(), moteus::Error> {
    // Auto-discovers transport on first use
    let mut ctrl = BlockingController::new(1);

    // Clear any faults
    ctrl.set_stop()?;

    // Send commands at regular intervals to prevent watchdog timeout
    loop {
        let result = ctrl.set_position(
            PositionCommand::new()
                .position(f32::NAN)
                .velocity(1.0)
                .accel_limit(0.5)
        )?;

        println!("Position: {} Velocity: {}", result.position, result.velocity);

        thread::sleep(Duration::from_millis(10));
    }
}
```

The `BlockingController` automatically discovers an available transport (fdcanusb, socketcan) on the first operation that needs it.

## Async Usage — AsyncController

For async applications, enable the `tokio` feature and use `AsyncController`:

```rust
use moteus::AsyncController;
use moteus::command::PositionCommand;

#[tokio::main]
async fn main() -> Result<(), moteus::Error> {
    // Auto-discovers transport on first use
    let mut ctrl = AsyncController::new(1);

    ctrl.set_stop().await?;

    loop {
        let result = ctrl.set_position(
            PositionCommand::new()
                .position(f32::NAN)
                .velocity(0.5)
        ).await?;

        println!("Position: {}", result.position);

        tokio::time::sleep(std::time::Duration::from_millis(10)).await;
    }
}
```

## Low-Level Usage — Controller

The `Controller` type provides frame building without any transport. This is useful for custom transports, embedded systems, or when you want full control over how frames are sent and received.

```rust
use moteus::{Controller, command::PositionCommand};

let controller = Controller::new(1);

// Build a position command
let cmd = controller.make_position_command(
    &PositionCommand::new().position(0.5).velocity(1.0),
    true  // request query response
);

// Convert to wire frame
let frame = cmd.into_frame();

// Send frame via your own transport...
// frame.arbitration_id, frame.data, frame.size
```

Parse responses back into query results:

```rust
use moteus::query::QueryResult;

// After receiving a response frame from transport...
let result = controller.parse_query(&response_frame)?;
println!("Mode: {:?}, Position: {}", result.mode, result.position);
```

## Custom Query Resolution

By default, only a limited set of registers are queried. To request additional registers, customize the `QueryFormat`:

```rust
use moteus::{BlockingController, Resolution, Register};
use moteus::query::QueryFormat;

let mut query_format = QueryFormat::default();
query_format.power = Resolution::Float;

let mut ctrl = BlockingController::new(1);
ctrl.controller.query_format = query_format;
```

For registers not in the standard `QueryFormat`, use the `extra` mechanism:

```rust
use moteus::{BlockingController, Resolution, Register};
use moteus::query::{QueryFormat, ExtraQuery};

let mut query_format = QueryFormat::default();
query_format.extra[0] = ExtraQuery {
    register: Register::Encoder1Position,
    resolution: Resolution::Float,
};

let mut ctrl = BlockingController::new(1);
ctrl.controller.query_format = query_format;
```

## Transport Configuration

### Auto-Discovery Options

Configure transport auto-detection with `TransportOptions`:

```rust
use moteus::{BlockingController, TransportOptions};
use std::time::Duration;

let opts = TransportOptions::new()
    .socketcan_interfaces(vec!["can0"])
    .timeout(Duration::from_millis(200));

let mut ctrl = BlockingController::with_options(1, &opts);
```

### Explicit Transport

You can also specify a transport directly:

```rust
use moteus::BlockingController;
use moteus::transport::socketcan::SocketCan;

let transport = SocketCan::new("can0")?;
let mut ctrl = BlockingController::new(1)
    .transport(transport);
```

## Diagnostics

The `DiagnosticStream` provides access to the moteus diagnostic protocol for reading and writing configuration:

```rust
use moteus::DiagnosticStream;

let mut stream = DiagnosticStream::new(1)?;

// Read a configuration value
let response = stream.command("conf get servo.max_current_A")?;
println!("{}", response);

// Write a configuration value
stream.command("conf set servo.max_current_A 30.0")?;
```

## Multi-Servo Coordinated Moves

The `move_to` function provides coordinated multi-servo motion:

```rust
use moteus::move_to::{move_to, MoveToOptions, Setpoint};

let setpoints = vec![
    Setpoint { id: 1, position: 0.5, velocity: None, max_torque: None },
    Setpoint { id: 2, position: -0.3, velocity: None, max_torque: None },
];

let opts = MoveToOptions::default();
move_to(&setpoints, &opts)?;
```

## API Reference

- [Rust API Reference](../reference/rust.md) — Curated summary of key types
- [moteus on docs.rs](https://docs.rs/moteus/) — Full auto-generated API documentation
- [moteus-protocol on docs.rs](https://docs.rs/moteus-protocol/) — Protocol crate documentation

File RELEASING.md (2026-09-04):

# Releasing moteus

Each shipped artifact (firmware, Python client, C++ client, Rust client)
carries its own [semver](https://semver.org/) version and its own release
cadence. Tags are prefixed by component:

| Component | Version source | Tag prefix |
|---|---|---|
| firmware  | `fw/moteus_hw.h` (`MOTEUS_FIRMWARE_VERSION`) | `firmware/v...` |
| python | `tools/python.bzl` (`VERSION`) | `python/v...` |
| cpp | `CMakeLists.txt` (`project(... VERSION ...)`) | `cpp/v...`  |
| rust | `lib/rust/Cargo.toml` (`[workspace.package] version`) | `rust/v...` |

Firmware, cpp, and rust pre-releases use semver suffixes (`1.0.0-rc.1`,
`1.0.0-beta.1`); the python package uses normalized PEP 440 forms instead
(`1.0.0rc1`, see [Python version strings](#python-version-strings)). For
firmware, the on-wire version (register 0x101) is the packed
`MAJOR.MINOR.PATCH` only,
so a `-rc.N` build of `1.0.0` reports exactly the same value over CAN as the
final `1.0.0`. They are ABI-equivalent on purpose; the build identity comes
from `fw/git_info.h` (commit SHA + dirty flag + timestamp).

## Firmware ABI version vs release version

`MOTEUS_FIRMWARE_VERSION` in `fw/moteus_hw.h` is the **firmware ABI
version** — what register 0x101 reports over CAN. It is independent of
the firmware release version (the `firmware/vX.Y.Z` git tag).

The ABI constant only bumps when the calibration process changes, or
configuration fields either change interpretation or require
conversion across upgrades.

By convention every ABI bump on this project has been
backwards-compatible in one direction: a newer client can talk to any
older firmware, but an older client cannot calibrate against newer
firmware and may or may not be able to successfully command a newer
firmware. So an ABI bump maps to a **MINOR** semver step. A real ABI
break that prevents new clients from talking to old firmware would be
MAJOR — that has not happened yet.

`SUPPORTED_ABI_VERSION` in `lib/python/moteus/moteus_tool.py` is the
highest firmware ABI that `moteus_tool --calibrate` knows how to handle.
In the source tree it tracks `MOTEUS_FIRMWARE_VERSION` exactly: when
firmware feature work bumps the ABI constant, the same commit (or
adjacent commit) bumps `SUPPORTED_ABI_VERSION` to match and adds the
new `FirmwareUpgrade.fix_config` rule.

The helper bumps both at once:

```bash
python3 utils/encode_firmware_version.py update \
    --firmware 1.1.0 --supported-abi 1.1.0
git commit -am "Bump firmware ABI to 1.1.0 for new <feature>"
```

`utils/release.py firmware <bump>` never modifies these constants. It
**validates** that `MOTEUS_FIRMWARE_VERSION`'s M.m is not greater than
the M.m of the release being tagged. The release's M.m may legitimately
move ahead of the ABI's M.m (a non-ABI-affecting MINOR release), but
the reverse — ABI ahead of release — would mean the firmware is
shipping with a newer ABI than its version number claims.

## When you do (and don't) need a Python release

The on-wire compatibility check that protects users is:

> published-moteus_tool `SUPPORTED_ABI_VERSION` ≥ firmware's reported
> ABI (register 0x101)

So:

- **Firmware patch release, no ABI change**: no Python release needed.
- **Firmware MINOR release, no ABI change**: no Python release needed.
- **Firmware MINOR release, ABI changed**: Python release needed so the
  published wheel knows about the new ABI. Treat it as a MINOR Python
  bump (it adds a capability — the tool now accepts firmwares it used
  to refuse).
- **Firmware MAJOR release**: Python release needed (still MINOR on the
  Python side; Python's own major version is a separate concern that
  moves only on Python API breaks).

Until the next Python release ships, users running `pip install moteus`
with the new firmware will hit the friendly "moteus_tool needs to be
upgraded" error from `SUPPORTED_ABI_VERSION` — which is correct
behavior, not a regression.

Python (and C++/Rust) releases are also of course necessary if the
functionality of the relevant library is improved or bugs are fixed.
The Rust client does not perform calibration, so it has no
`SUPPORTED_ABI_VERSION` concern — like C++, it only needs a release
when its own functionality changes.

## Cutting a release

`release.py` refuses to tag unless `CHANGELOG.md` has a `### X.Y.Z`
section with entries under the component being released -- rename the
component's `### Unreleased` heading first.  (Entries themselves are
added with the change that introduces them, not at release time.)

Run the helper from the repo root, then push:

```bash
# patch bump (1.0.0 -> 1.0.1)
utils/release.py firmware patch

# minor bump
utils/release.py python minor

# start a pre-release cycle (explicit)
utils/release.py firmware 1.1.0-rc.1

# iterate a pre-release (1.1.0-rc.1 -> 1.1.0-rc.2)
utils/release.py firmware rc

# graduate a pre-release to its final release (1.1.0-rc.2 -> 1.1.0)
utils/release.py firmware patch
```

The `patch` bump is overloaded for convenience: when current is already a
pre-release, it strips the suffix instead of incrementing the patch byte
(matches npm/cargo conventions). `minor` and `major` always advance
M.m.p as you'd expect, regardless of any pre-release suffix.

The script:

1. Determines the current release version (from the latest `firmware/v*`
   tag for firmware, or from the version file for python/cpp).
2. Computes the new version (or accepts an explicit one).
3. For firmware: validates `MOTEUS_FIRMWARE_VERSION` matches the new
   release's M.m.p; refuses to tag otherwise.
4. For python/cpp/rust: updates the version file(s) in place. For rust
   this is `lib/rust/Cargo.toml` (the workspace version plus the
   inter-crate dependency requirements) and the matching package
   entries in `lib/rust/Cargo.lock`.
5. Commits (if the files changed) and creates the annotated tag.
6. Prints the `git push` commands.

Inspect the diff and tag before pushing.

```bash
git push origin HEAD
git push origin firmware/v1.0.1
```

The matching `build-<component>-release` workflow then builds the
artifact and creates a GitHub Release **as a draft**.  Drafts are not
visible to users browsing the Releases page or to `pip`/`FetchContent`
consumers — they exist only on the maintainer's view of the page.

You can also kick off a release from the GitHub UI via the
[`Release`](.github/workflows/release.yml) workflow — it runs the same
script in CI, useful when releasing from somewhere without your local
toolchain.

## Promoting a draft release to public

After the build workflow finishes, validate the draft locally:

1. Go to the repo's Releases page → the draft will show under "Draft"
   at the top.  Download the attached artifacts.
2. For firmware: flash on representative hardware and run your
   validation suite.  For python: `pip install` the wheel into a fresh
   venv and exercise `moteus_tool` against a device.  For cpp: build a
   downstream project against the tag.  For rust: build a downstream
   project against the tag (`moteus = { git = ..., tag = "rust/vX.Y.Z" }`)
   and exercise it against a device.
3. When satisfied, publish.  Either click "Publish release" in the UI,
   or:

   ```bash
   gh release edit firmware/v1.0.0 --draft=false
   ```

If something is wrong, abort instead of publishing:

```bash
gh release delete firmware/v1.0.0 --yes
git push --delete origin firmware/v1.0.0
git tag -d firmware/v1.0.0
# ...fix the issue, then re-tag
```

For python, **promoting the draft is what triggers the PyPI publish**.
The `publish-python-pypi.yml` workflow listens for the `release:
published` event, downloads the wheel and sdist attached to the
release, and uploads them to PyPI via OIDC. Do not click "Publish
release" on a python draft until you intend the wheel to land on
PyPI — PyPI is append-only, you cannot un-publish.

Likewise for rust, **promoting the draft is what triggers the
crates.io publish**. The `publish-rust-crates.yml` workflow checks out
the release tag and runs `cargo publish --workspace` via OIDC trusted
publishing. crates.io is also append-only — a published version can be
yanked but never deleted or reused.

## Cutting a maintenance branch

After every firmware MAJOR or MINOR release, cut a maintenance branch so
that future bugfixes can be backported to it without dragging in unrelated
`main` work:

```bash
utils/cut_release_branch.py firmware/v1.0.0
git push origin release/firmware-1.0.x
```

For a 1.0.1 patch release: land the fix on `main`, then:

```bash
git checkout release/firmware-1.0.x
git cherry-pick <sha>
utils/release.py firmware patch
git push origin HEAD release/firmware-1.0.x
git push origin firmware/v1.0.1
```
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

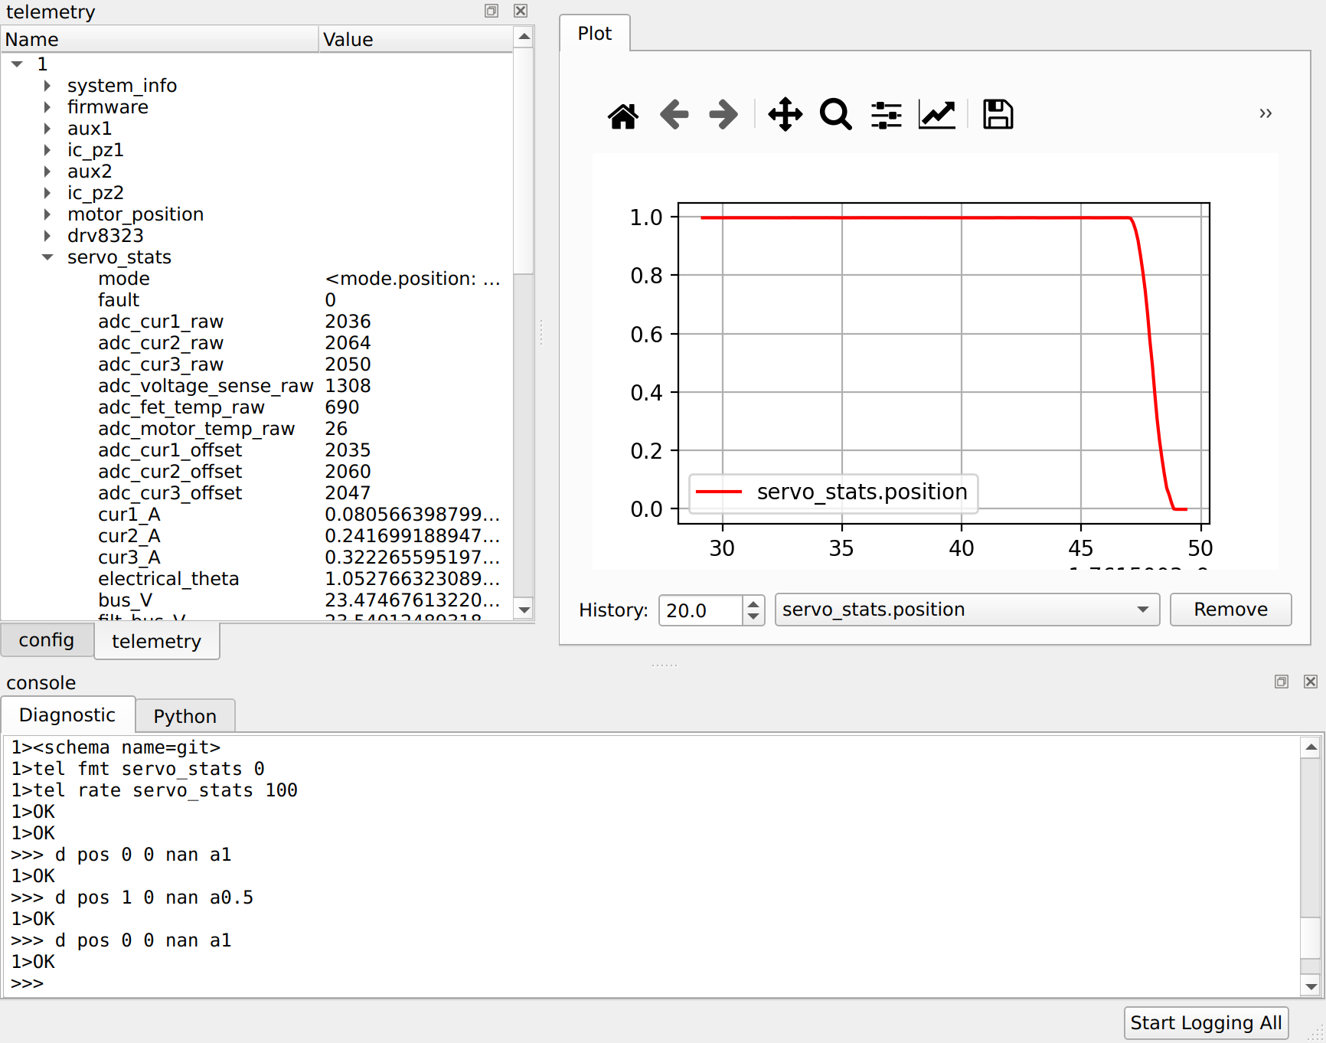
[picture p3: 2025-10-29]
docs/guides/images/tview-overview-orig.png

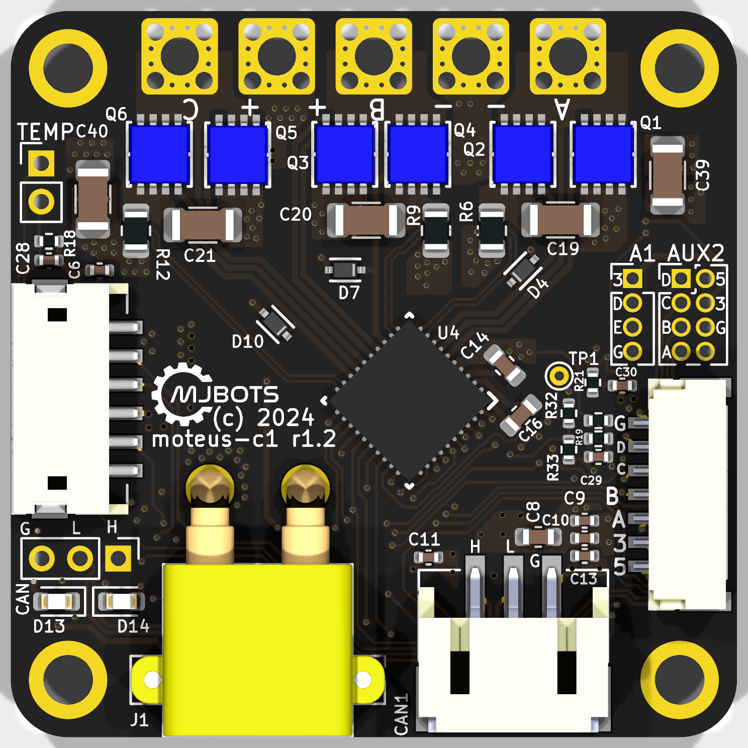
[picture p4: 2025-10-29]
docs/reference/c1/moteus-c1-base.png

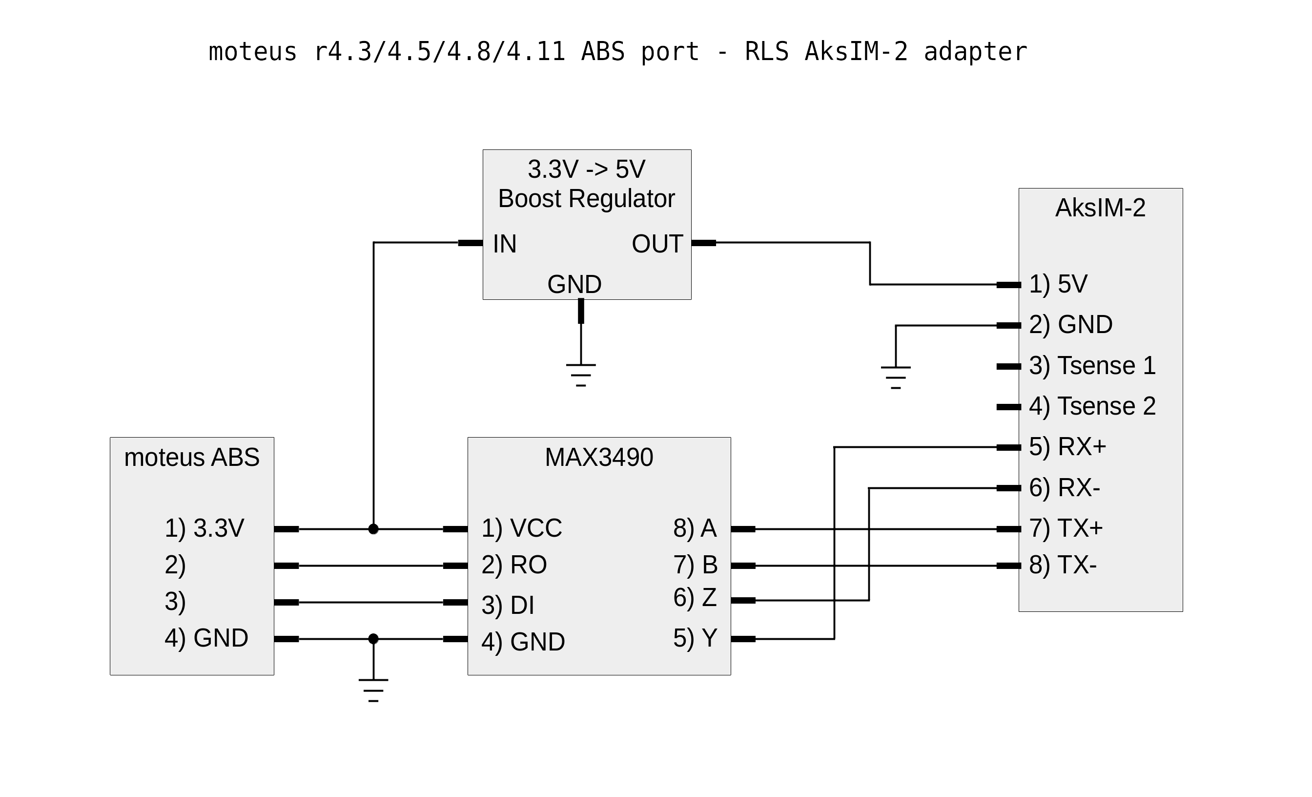
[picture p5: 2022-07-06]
docs/aksim2_adapter.png

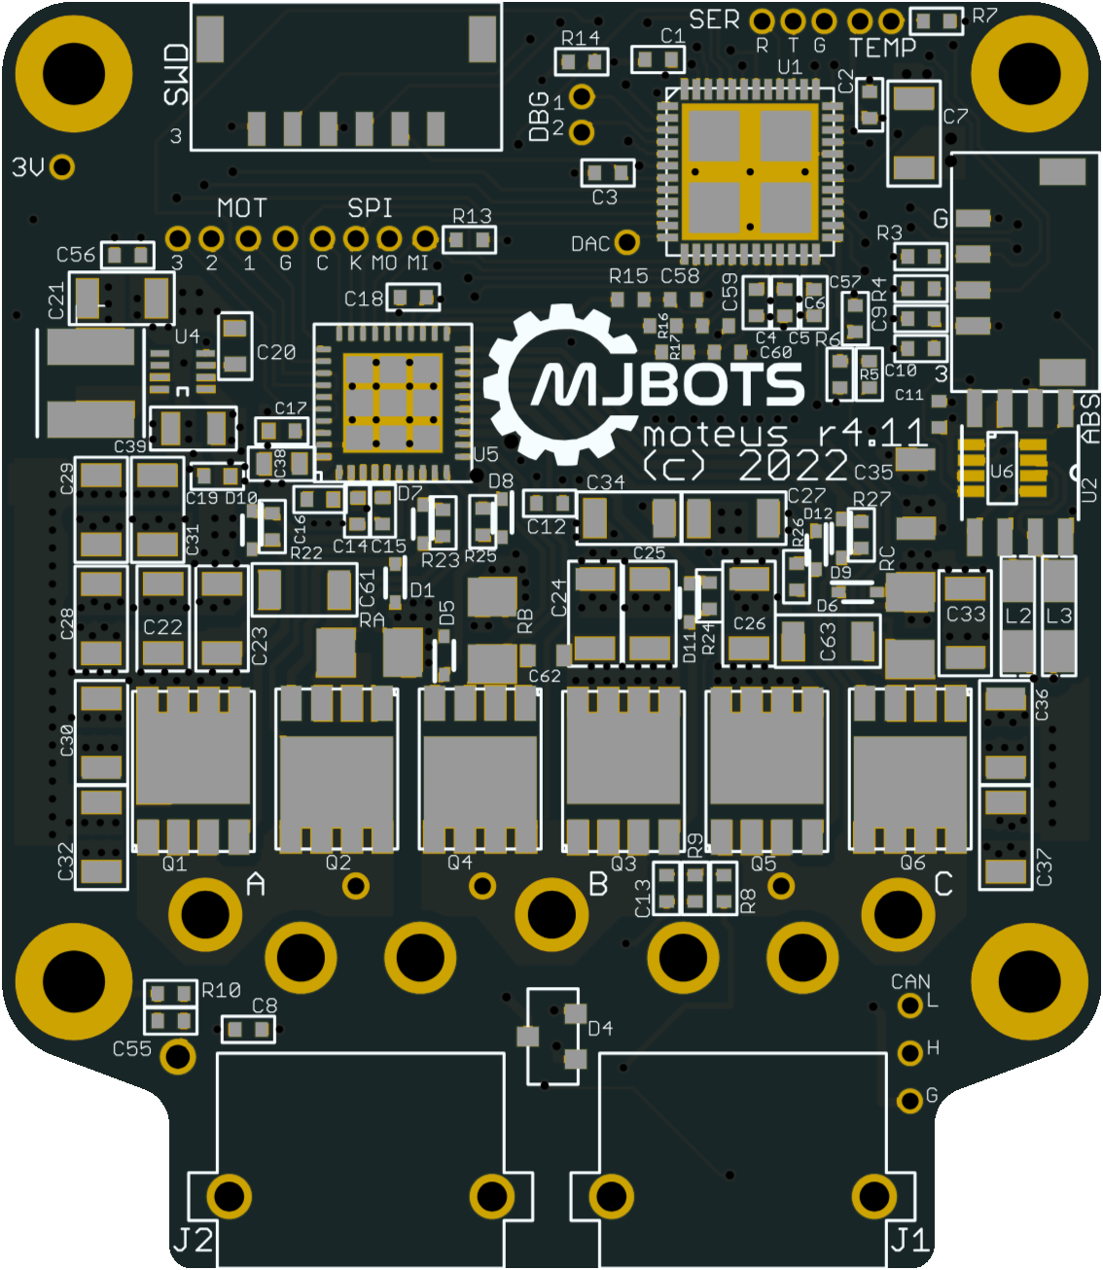
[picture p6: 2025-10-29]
docs/reference/r4/moteus-r4-front-base.png

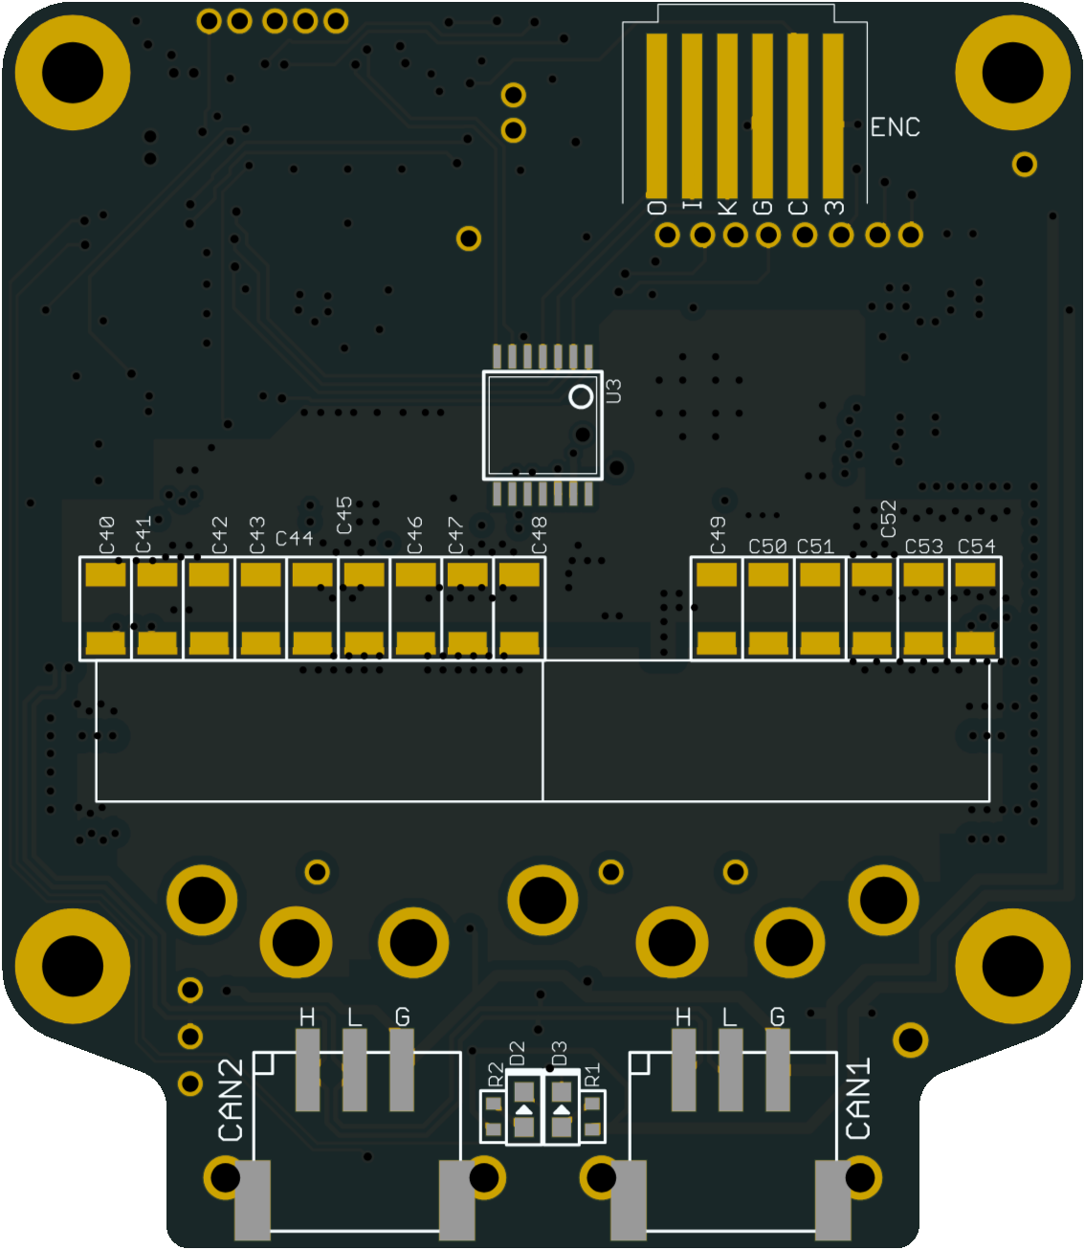
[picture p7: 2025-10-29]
docs/reference/r4/moteus-r4-back-base.png

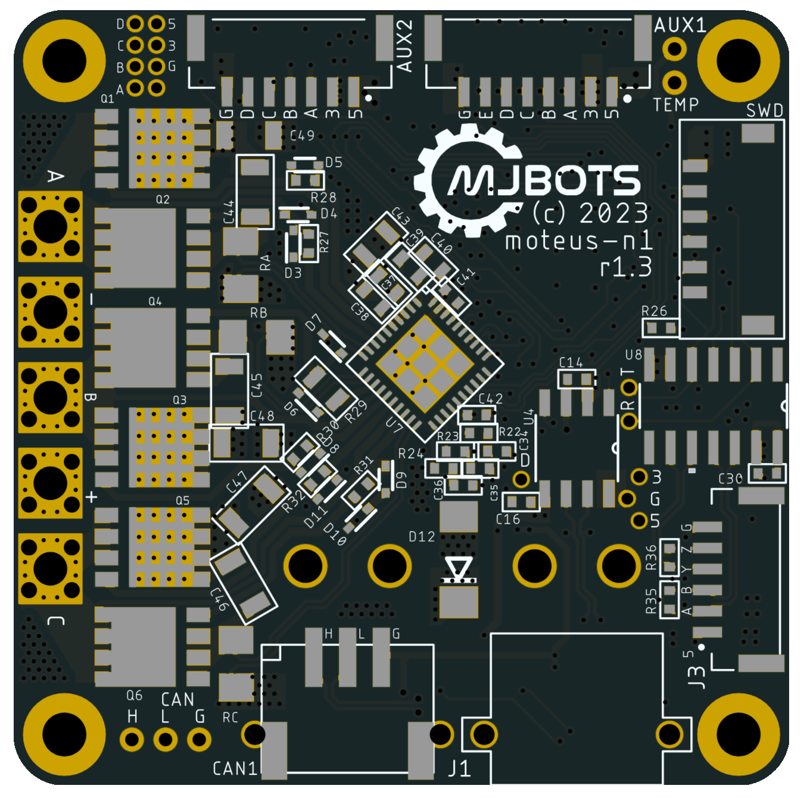
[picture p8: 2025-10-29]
docs/reference/n1/moteus-n1-base.png

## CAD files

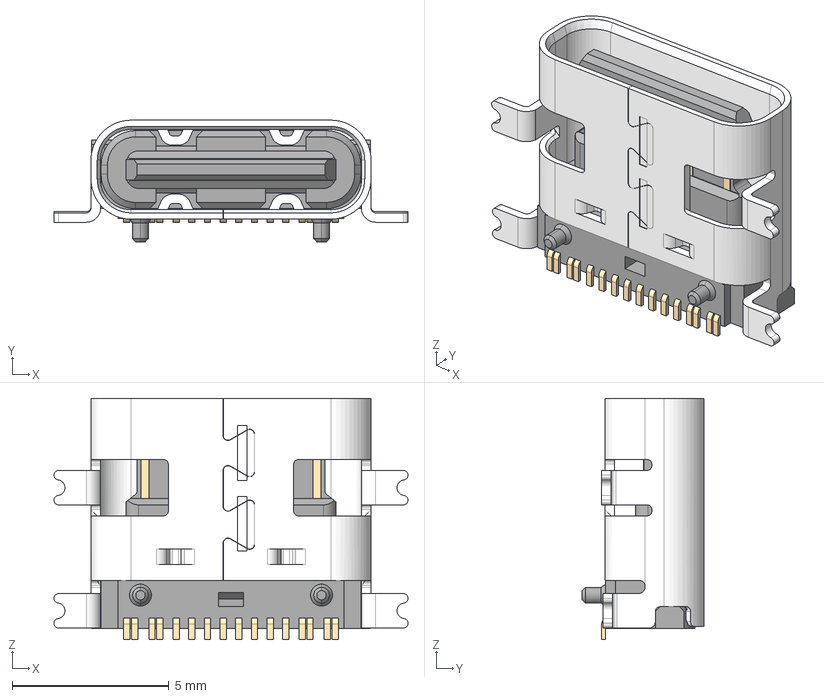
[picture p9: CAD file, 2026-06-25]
hw/mjuart/3d/usb4110-gf-a.stp
11.3 x 3.89 x 7.70 mm

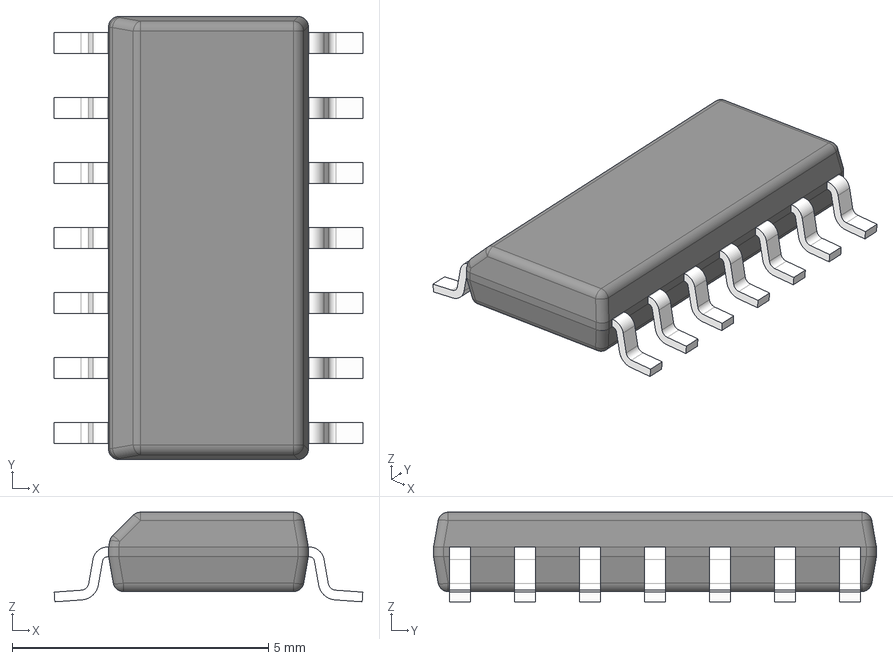
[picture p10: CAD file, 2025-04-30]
hw/x1/3d/D0014A.stp
6.03 x 8.65 x 1.75 mm
BODY-SO
LEAD-SO x 14
PIN1-ID

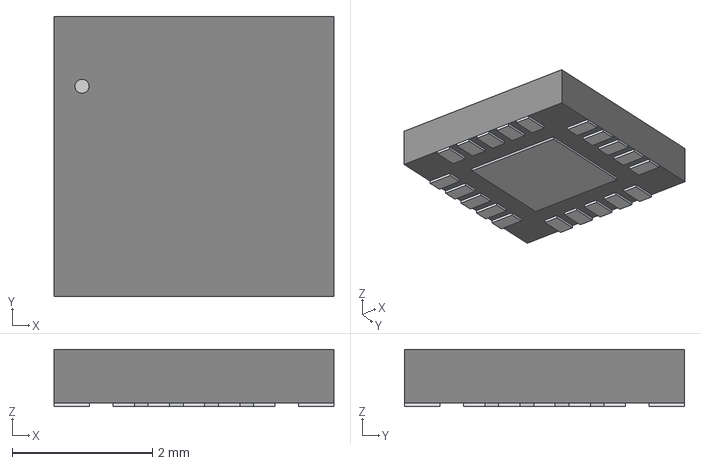
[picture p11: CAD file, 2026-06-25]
hw/mjuart/3d/QFN20_FT231XQ_FTD.step
3.99 x 3.99 x 0.815 mm

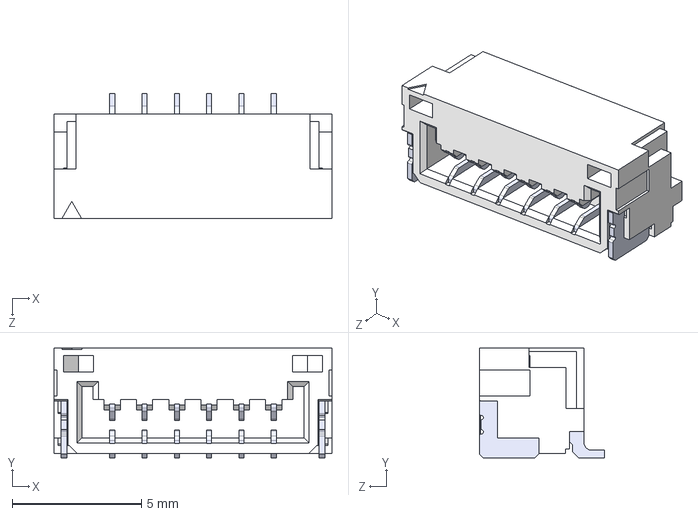
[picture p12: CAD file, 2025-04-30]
hw/x1/3d/SM06B-GHS-TB.step
10.8 x 4.25 x 4.85 mm
SMxB-GHS-TB_06
pin x 6

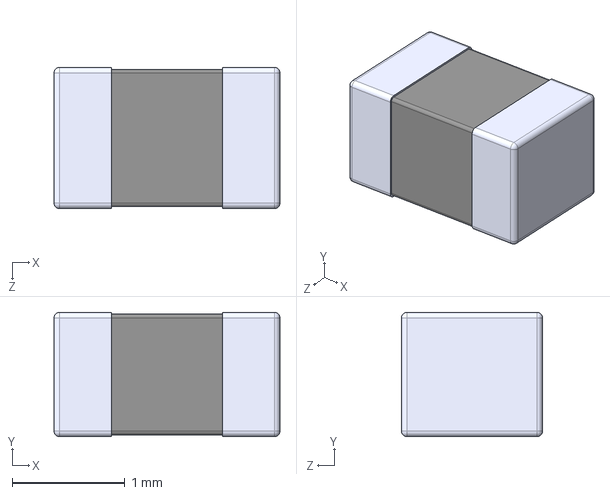
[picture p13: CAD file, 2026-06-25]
hw/mjuart/3d/MI0805K400R-10.step
2.00 x 1.10 x 1.25 mm

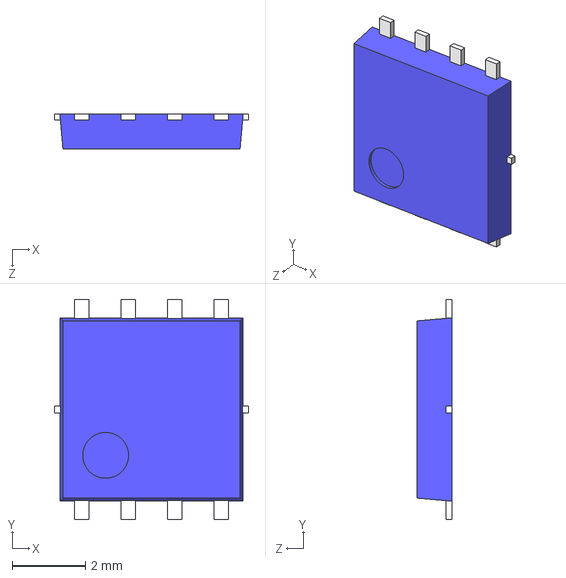
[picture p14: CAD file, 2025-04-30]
hw/x1/3d/SOP_Advance.step
5.30 x 6.00 x 0.95 mm

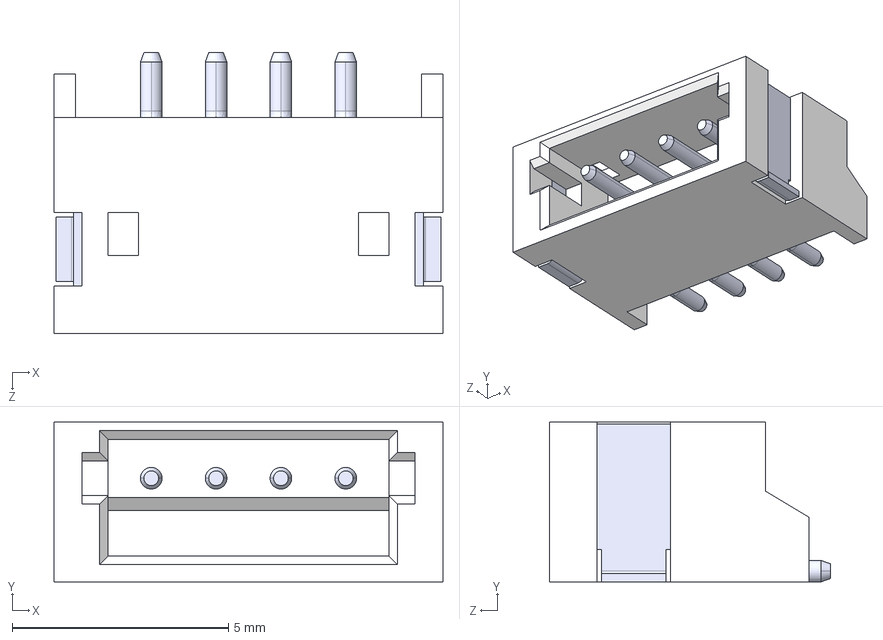
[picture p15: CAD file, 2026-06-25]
hw/mjuart/3d/S4B-ZR-SM4A-TF.STEP
9.00 x 3.70 x 6.50 mm

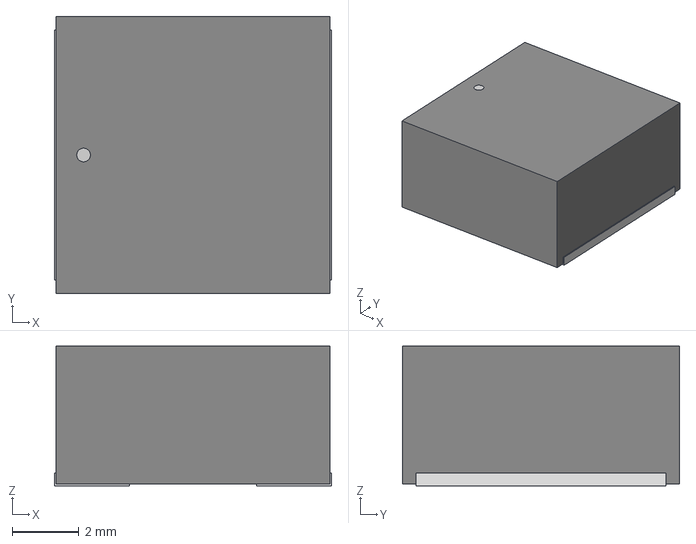
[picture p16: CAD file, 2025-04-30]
hw/x1/3d/IND_8040-WE-LQS_WRE.step
8.31 x 8.31 x 4.19 mm

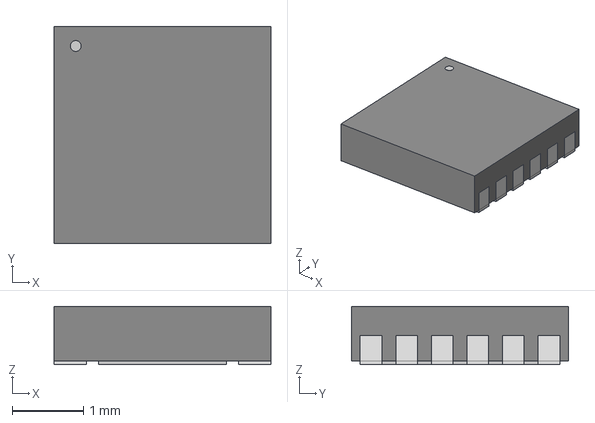
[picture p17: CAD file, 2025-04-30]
hw/x1/3d/21-0664E_1233-1C_MXM.step
3.05 x 3.05 x 0.815 mm

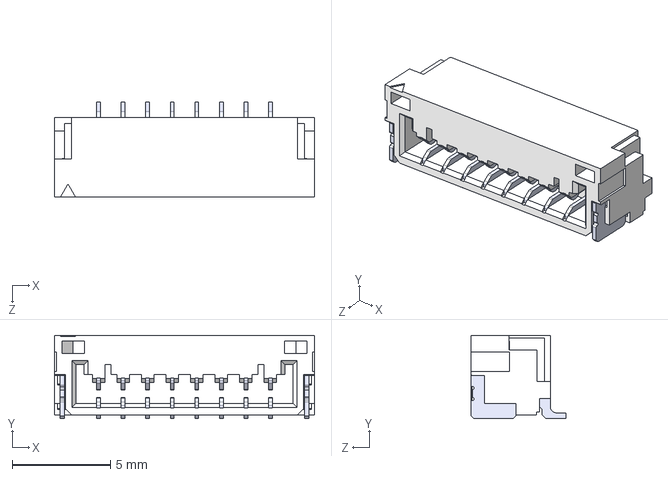
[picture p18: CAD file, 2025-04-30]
hw/x1/3d/SM08B-GHS-TB.STEP
13.2 x 4.25 x 4.85 mm
SMxB-GHS-TB 8plus_8
pin x 8

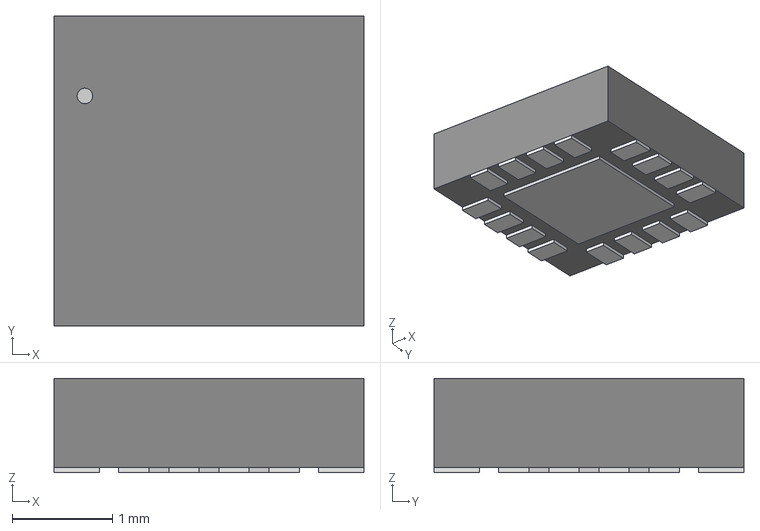
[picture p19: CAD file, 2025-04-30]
hw/x1/3d/QFN-16_MA600_MNP.step
3.10 x 3.10 x 0.942 mm

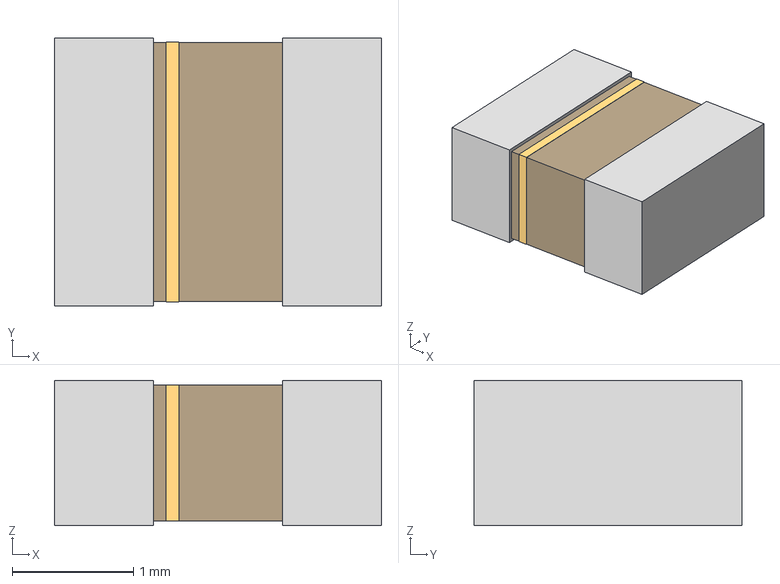
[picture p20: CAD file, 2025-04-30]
hw/x1/3d/IND_DFE252012_MUR.step
2.69 x 2.21 x 1.19 mm

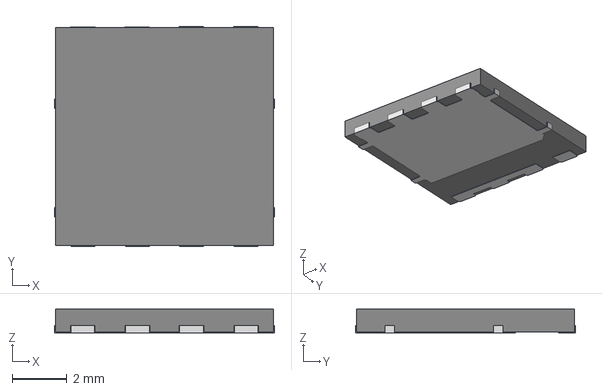
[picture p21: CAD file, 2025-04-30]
hw/x1/3d/FDMT80080DC.stp
8.07 x 8.06 x 0.879 mm

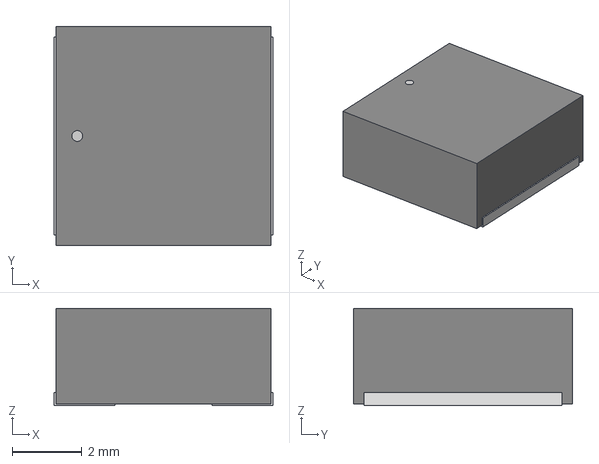
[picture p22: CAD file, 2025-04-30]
hw/x1/3d/IND_6028-WE-LQS_WRE.step
6.30 x 6.30 x 2.80 mm

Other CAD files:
hw/x1/3d/XT60PW-M.step
hw/x1/3d/DRL0008A.stp
hw/x1/3d/DDA0008E.stp
hw/x1/3d/SM07B-GHS-TB-LF--SN---3DModel-STEP-56544.STEP
hw/c1/r1.2/20240305-moteus-c1-r1_2.step
hw/controller/r4.3/20200729-moteus-controller-r43-mechanical.step
hw/controller/r4.5/20210124-moteus-controller-r45-mechanical.step
hw/n1/r1.2/20230226-moteus-n1-mechanical.step
hw/n1/r1.3/20230523-moteus-n1-r1_3-mechanical.step
hw/x1/3d/21-0487A_MXM.step
hw/x1/3d/DRB0008F.stp
hw/x1/3d/DSE0006A.stp
hw/x1/3d/IND_4018-WE-LQS_WRE.step
hw/x1/3d/RTA0040B.stp
hw/x1/3d/S3B-PH-SM4-TB_LF__SN_.step
hw/x1/3d/S6B-ZR-SM4A-TF_LF__SN_.step
hw/x1/3d/SOD-523_STM.step
hw/x1/3d/TSON Advance.step
hw/x1/3d/TSSOP14_OSM.step
hw/x1/3d/UFQFPN-48_7X7X0P55MM.step
hw/x1/3d/XT30PW-M.step
hw/x1/r1/20250427-moteus-x1-r1.step

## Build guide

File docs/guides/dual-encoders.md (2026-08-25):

# Dual Encoder Configuration

Often moteus is used in applications where a gearbox or other reducer is used between the rotor and the final plant.  In those situations it can be valuable to have a secondary encoder measuring the output of the reducer:

**Absolute positioning**: With only an encoder on the rotor, it is not possible to know absolutely where the output is.

**Improved accuracy or sensing performance**: The onboard encoder included with moteus is sufficient for commutation for nearly all motors, however some applications may require lower position or velocity sensing noise or higher resolution in order to achieve accurate very slow movements, or very accurate positioning.

This section will cover how to set up several common dual encoder configurations.

## Important factors when configuring dual encoders

1. **Sign match**: moteus requires that the sign of all encoders match.  Those must be configured manually in `motor_position.sources.X.sign`.  To verify the signs are correct, plot `motor_position.sources.X.filtered_value` for all configured encoders, spin the system by hand, and verify that all plots move in the same direction.

2. **Offset match**: If the absolute values of multiple encoders must be related, such as for a disambiguation configuration, then the offsets must be matched so that the encoders read 0 at the same time.  These offsets must be manually configured in `motor_position.sources.X.offset`.  To verify they are correct, plot `motor_position.sources.X.filtered_value` for all configured encoders, spin the system by hand to the zero point, and verify that all encoders read 0.

## Onboard + 8x reducer + MA600 on-axis - Disambiguation

In this configuration, the rotor is sensed with the moteus onboard encoder and the output is sensed with an MA600 on-axis encoder.  Assuming low backlash, the output positioning is performed from the onboard encoder and the output encoder is only used for disambiguation.  This results in the best performance since the effective resolution of the onboard encoder is multiplied by the gear reduction and will be much better than the MA600 on the output.

The MA600 is attached to the aux2 port on one of the moteus-c1 [(c1 pinout)](../reference/pinouts.md#moteus-c1), moteus-n1 [(n1 pinout)](../reference/pinouts.md#moteus-n1), or moteus-x1 [(x1 pinout)](../reference/pinouts.md#moteus-x1).

This pinout is the one accomplished if using the cable included with the [mjbots MA600 breakout board](https://mjbots.com/products/ma600-breakout).

If starting from a factory default configuration, first, configure the
aux2 port:

```
aux2.pins.0.mode 1  # spi
aux2.pins.1.mode 1  # spi
aux2.pins.2.mode 1  # spi
aux2.pins.3.mode 2  # spi_cs
aux2.spi.mode 5     # ma600
aux2.spi.rate_hz 6000000
aux2.uart.mode 0    # disable serial control
```

Then, configure motor_position:

```
motor_position.sources.1.aux_number 2
motor_position.sources.1.type 1
motor_position.sources.1.cpr 65536
motor_position.sources.1.reference 1  # output
motor_position.rotor_to_output_ratio 0.125
motor_position.output.reference_source 1
```

The sign and offset of the MA600 will need to be matched to the onboard encoder as per [the above section](#match).

## Onboard + 10x reducer + AksIM-2 on output

In this configuration, the onboard encoder is used to sense the rotor, and an AksIM-2 encoder from RLS is used on the output.  The AksIM-2 has much better accuracy and noise performance than the onboard on-axis encoder, and thus this configuration could be used for applications where either very accurate positioning is required, or very precise low speeds are required.

The AksIM-2 is attached to the GH-6 RS422 connector on a moteus-n1 [(n1 pinout)](../reference/pinouts.md#moteus-n1) or moteus-x1 [(x1 pinout)](../reference/pinouts.md#moteus-x1).

moteus is compatible with AksIM-2 encoders configured as follows:

- **Communication Interface**: SF - Asynchronous Serial, RS422, 5V
- **Communication Protocol Variant**: F - 1000 kbps
- **Resolution**: <= 19B, no multiturn support

If starting from a factory default configuration, first configure the aux1 port.

```
aux1.pins.3.mode 3 # uart
aux1.pins.4.mode 3 # uart
aux1.uart.mode 1 # aksim2
aux1.uart.baud_rate 1000000
aux1.rs422 1
```

Then configure motor_position:

```
motor_position.rotor_to_output_ratio 0.1
motor_position.sources.1.aux_number 1
motor_position.sources.1.type 2          # uart
motor_position.sources.1.cpr 4194304     # used by moteus for all AksIM-2
motor_position.sources.1.reference 1     # output
motor_position.output.source 1
```

The sign and offset of the AksIM-2 will need to be matched to the onboard encoder as per [the above section](#match).

## Hall + 10x reducer + Off axis MA600

In this configuration, hall effect encoders are used to sense commutation and an MA600 is used in conjuction with a diametrically magnetized ring magnet for output positioning.  It is designed as one of the lowest cost options for a hollow axis actuator with a gear reduction, as the off-axis MA600 has minimally acceptable performance as does the hall effect sensors.

The MA600 is connected to AUX1 on a moteus-n1 [(n1 pinout)](../reference/pinouts.md#moteus-n1) or moteus-x1 [(x1 pinout)](../reference/pinouts.md#moteus-x1) and the hall effect sensors are connected to AUX2.

First, we will configure the hall effect sensors and calibrate them.

```
aux2.pins.0.mode 6  # hall
aux2.pins.0.pull 1  # pull_up
aux2.pins.1.mode 6  # hall
aux2.pins.1.pull 1  # pull_up
aux2.pins.2.mode 6  # hall
aux2.pins.2.pull 1  # pull_up
aux2.hall.enabled 1
motor_position.rotor_to_output_ratio 0.1
motor_position.sources.0.aux_number 2
motor_position.sources.0.type 4  # hall
```

Then, the hall effect sensors are calibrated:

```
python -m moteus.moteus_tool -t 1 --calibrate --cal-motor-poles 30
```

Now we will configure the MA600.

```
aux1.pins.0.mode 1  # spi
aux1.pins.1.mode 1  # spi
aux1.pins.2.mode 1  # spi
aux1.pins.3.mode 2  # spi_cs
aux1.spi.mode 5     # ma600
aux1.spi.rate_hz 6000000
aux1.uart.mode 0    # disable serial control
motor_position.sources.1.aux_number 1
motor_position.sources.1.type 1  # spi
motor_position.sources.1.cpr 65536
motor_position.sources.1.reference 1  # output
```

Then, before configuring the MA600 to be used for output, match the sign of the MA600 and hall effects according to [the procedure here](#match).

For an off-axis MA600, BCT tuning should be performed, and non-linear compensation may be performed.

```
moteus$ ./utils/measure_ma732_bct.py
```

To peform non-linear compensation, you can use:

```
moteus$ ./utils/compensate_encoder.py
```

Finally, the MA600 can be configured as the output source:

```
motor_position.output.source 1
```

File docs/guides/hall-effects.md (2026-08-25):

# Motor with Hall Effect Sensors

Many motors include hall effect sensors used to provide commutation information to motor controllers.  moteus is able to use hall effect sensors for both commutation and output positioning.  First, some caveats:

**They may not be needed**: Just because a motor has hall effect sensors built in, does not mean you need to use them.  If you can use the on-axis magnetic encoder integrated into moteus by mounting moteus appropriately relative to the rotor, that will always give better results than using hall effect encoders.

**You will likely need additional hardware**: Most configurations with hall effects will require additional filtering capacitors, placed near moteus, between each signal line and ground.  1nF is a recommended starting point.  They can be added either in the wire harness, or on unpopulated 0402 pads on the moteus-c1, moteus-n1, and moteus-x1.

**Hall effect sensors used for output positioning have very poor low velocity performance**: While hall effect sensors are minimally useful for commutation and higher speed output operation, they will provide poor performance when used as an output encoder at low speeds.  That means many position control applications, which are inherently often at low speed, will give poor results.

**moteus-r4 cannot easily drive many hall effect sensors**: moteus-r4 specifically has only 3.3V supply for external devices, whereas most hall effect encoders require 5V.  Further, the only means of connecting hall effect sensors to moteus-r4 are using unpopulated pads on the back of the board, and *not* using the onboard encoder.  Other moteus products do not have these specification limitations regarding supply voltage and connectors.

If using hall effects for commutation or output positioning is still desired, the below configurations can get you started.

## aux2 configuration ##

This configuration uses hall effect sensors connected to the aux2 GH7
connector for both commutation and output positioning.

moteus-c1 [(c1 pinout)](../reference/pinouts.md#moteus-c1), moteus-n1 [(n1 pinout)](../reference/pinouts.md#moteus-n1), and moteus-x1 [(x1 pinout)](../reference/pinouts.md#moteus-x1) all have an aux2 GH7 connector that can provide 5V output and has 5V tolerant IO pins.  The typical wiring diagram looks like the below, although the hall connector is "nominal" as there is no real standard:

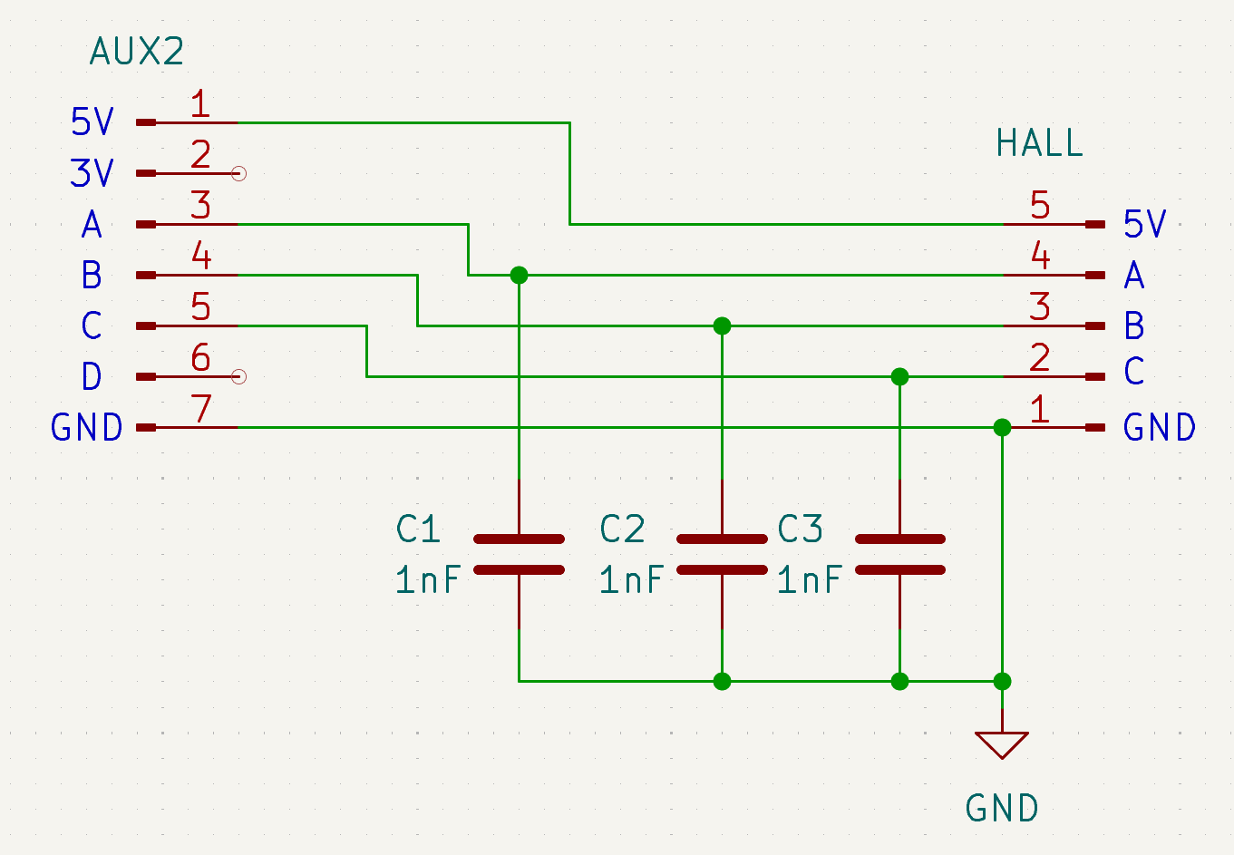
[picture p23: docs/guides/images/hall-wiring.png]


As mentioned above, either 1nF capacitors should be installed in the harness between each signal line and ground, or installed on the appropriate unpopulated pads on the board.

The following aux2 configuration parameters should be set.

```
aux2.pins.0.mode 6  # hall
aux2.pins.0.pull 1  # pull_up
aux2.pins.1.mode 6  # hall
aux2.pins.1.pull 1  # pull_up
aux2.pins.2.mode 6  # hall
aux2.pins.2.pull 1  # pull_up
aux2.hall.enabled 1
aux2.uart.mode 0    # disable serial control
```

Then motor_position is configured as follows:

```
motor_position.sources.0.aux_number 2
motor_position.sources.0.type 4  # hall
```

Finally, when calibrating, the number of poles is required to be
specified.

```
python -m moteus.moteus_tool -t 1 --calibrate --cal-motor-poles 30
```

## Advanced: Dual Encoder Setup

A more performant configuration may use the hall effect sensors for commutation and a different encoder measuring the output position.  That is not directly described here, but you can look at the [Dual Encoders](dual-encoders.md) guide as well as the [encoder reference](../reference/encoders.md) to understand how to configure it.

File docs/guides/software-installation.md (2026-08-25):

# Software Installation

This guide covers installing the software tools needed to communicate with and configure your moteus controller.

## Installing moteus_gui

The moteus_gui package provides essential tools including `tview` (telemetry viewer) and `moteus_tool` (configuration utility). Installation varies slightly by platform.

=== "Linux"

    ```bash
    python -m pip install moteus-gui
    ```

    **Note**: On Linux, you may need to use either a [virtual environment](https://docs.python.org/3/library/venv.html#creating-virtual-environments) or the `--break-system-packages` option.

    **fdcanusb udev rules**: If using the fdcanusb or mjcanfd-usb-1x adapter, you may need to set up udev rules so regular users can access the device. Follow the instructions at: [https://github.com/mjbots/fdcanusb/blob/master/70-fdcanusb.rules](https://github.com/mjbots/fdcanusb/blob/master/70-fdcanusb.rules)

=== "Windows"

    ```bash
    python -m pip install moteus-gui
    ```

    **Note**: On some older Windows installations, you need to invoke python as `python3`, not `python`.

=== "macOS"

    ```bash
    python -m pip install moteus-gui
    ```

=== "Raspberry Pi (cmdline only)"

    ```bash
    python -m venv moteus-venv --system-site-packages
    ./moteus-venv/bin/pip install moteus

    ```

    **Note**: For complete Raspberry Pi setup instructions including GUI and hardware configuration, see [Raspberry Pi Setup](../platforms/raspberry-pi.md).

## Running tview

tview is the primary tool for configuring and inspecting the state of your moteus controller. Launch it with:

```bash
python3 -m moteus_gui.tview
```

**Alternative**: Your pip installation may have added a `tview` script to your PATH, which you can use instead.

**UART**: To use tview with a logic-level UART, the serial port device
must be manually specified:

=== "Linux"

    ```bash
    python3 -m moteus_gui.tview --fdcanusb /dev/serial/by-id/usb-FTDI_FT231X_USB_UART_DP050AG5-if00-port0
    ```

=== "Windows"

    ```bash
    python3 -m moteus_gui.tview --fdcanusb COM2
    ```

For information on connectors and cabling required for UART, see the [UART integration guide](../integration/uart.md).

## Understanding tview

tview has three main panes: left, right, and bottom.

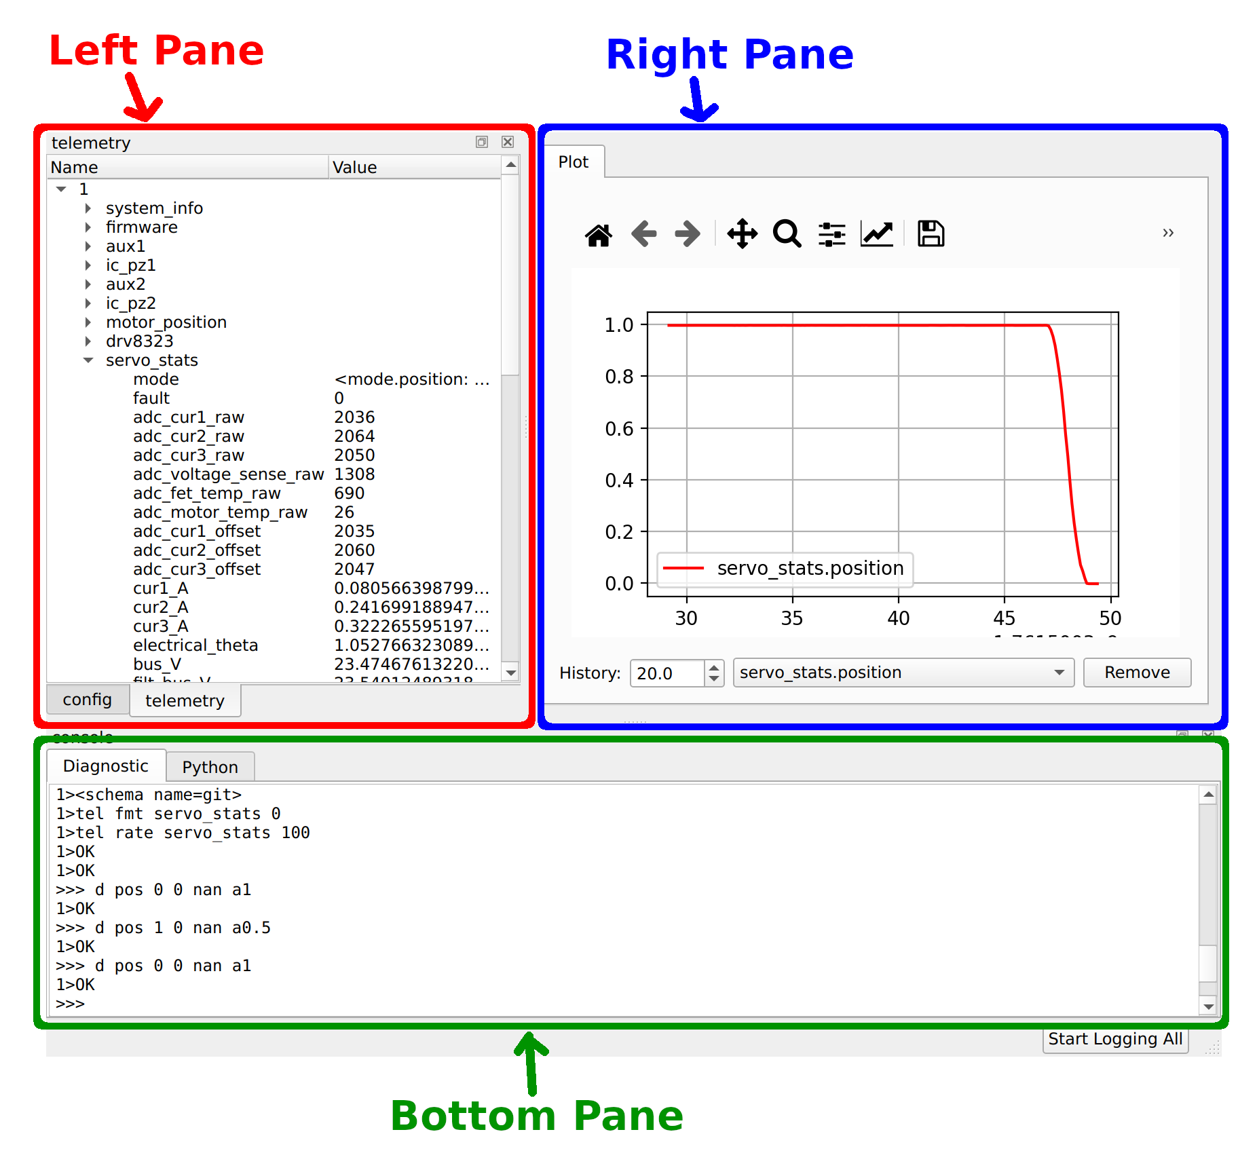
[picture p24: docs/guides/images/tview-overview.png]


### Left Pane Tabs

The left pane contains two tabs:

**Right tab (default)**: Shows a hierarchical tree of all telemetry items currently being reported by the controller.

**Left tab**: Shows a hierarchical tree of all configurable parameters. You can update parameter values by double-clicking on their value and entering a new one.

### Right Pane

The right pane displays real-time plots of telemetry items. You can populate it with plots by right-clicking on telemetry items in the telemetry tab (left pane, right tab).

### Bottom Pane

The bottom pane contains two tabs:

**Left tab - console (default)**: a command line console showing the moteus diagnostic protocol.  It:

- Shows commands sent internally by tview and their responses
- Provides an interactive console to interact with the device using the [diagnostic protocol](../protocol/diagnostic.md)

**Right tab - Python**: A python REPL that can be used to interact with the the controller(s) using the moteus python library.

## Next Steps

Now that you have the software installed and understand the tview interface, proceed to the [Configuration](configuration.md) guide to set up your moteus controller for your specific motor and application.

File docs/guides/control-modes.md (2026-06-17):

# Control Modes

The moteus controller offers flexible control modes to suit different robotics applications. By adjusting control gains and command parameters, you can optimize the controller for various use cases—from precise positioning and velocity control to high-bandwidth torque applications. This guide covers the recommended configurations for common control scenarios.

## Understanding Position Mode

The primary control mode for the moteus controller is an integrated position/velocity controller. The semantics of the control command are somewhat unorthodox, so as to be easily amenable to idempotent commands sent from a higher level controller. Each command includes the following parameters:

- **Position**: The desired position in revolutions
- **Velocity**: The rate at which the desired position changes in revolutions/s
- **Maximum torque**: Never use more than this amount of torque when controlling
- **Feedforward torque**: Give this much extra torque beyond what the normal control loop says
- **Stop position**: If non-special, never move the desired position away from this target
- **kp scale**: Scale the proportional constant by this factor
- **kd scale**: Scale the derivative constant by this factor
- **ilimit scale**: Scale the integrative limit by this factor
- **Velocity limit override**: If non-special, override the configured velocity limit, which constrains how quickly the target position is reached
- **Acceleration limit override**: If non-special, override the configured acceleration limit, which constrains how quickly the target position is reached

Additionally, the position may be set as a "special value" (NaN for floating point and the debug interface, maximal negative for integer encodings). In that case, the position selected is "wherever you are right now".

## Constant Acceleration Trajectories

Velocity and acceleration limits can be configured either globally, or
on a per-command basis which will cause moteus to internally generate
continuous acceleration limited trajectories to reach the given
position and velocity.  Once the trajectory is complete, the command
velocity is continued indefinitely.

=== "Diagnostic Protocol"

    ```
    # Move to position 1 then stop.  Accelerate/decelerate at 2Hz/s
    # and use a maximum velocity of 0.5Hz.
    d pos 1 0 nan a2 v0.5
    ```

=== "Python"

    ```python
    await controller.set_position(
        position=1,
        velocity=0,
        accel_limit=2,
        velocity_limit=0.5,
    )
    ```

=== "C++"

    ```cpp
    mjbots::moteus::Controller::Options options;
    options.position_format.accel_limit = mjbots::moteus::kFloat;
    options.position_format.velocity_limit = mjbots::moteus::kFloat;

    mjbots::moteus::Controller controller(options);

    mjbots::moteus::PositionMode::Command cmd;
    cmd.position = 1.0;
    cmd.velocity = 0.0;
    cmd.accel_limit = 2.0;
    cmd_velocity_limit = 0.5;

    auto result = controller.SetPosition(cmd);
    ```

Default values for acceleration and velocity limits can also be set in
configuration.

* `servo.default_accel_limit`
* `servo.default_velocity_limit`

## Velocity Control

To implement a velocity controller, each command should have the
"position" set to NaN (or equivalent integral encoding).  It is
recommended to configure `servo.max_position_slip` to a finite value
greater than or equal to 0 ([reference](../reference/configuration.md#servomax_position_slip)).
When it is larger, more external disturbances will be rejected, but
the controller will also "catch up" when the magnitude of external
disturbances is decreased.

**Example:**

=== "Diagnostic Protocol"

    ```
    d pos nan 2 nan
    ```

=== "Python"

    ```python
    await controller.set_position(
        position=math.nan,  # NaN for velocity mode
        velocity=2.0,       # 2 revolutions/second
        query=True
    )
    ```

=== "C++"

    ```cpp
    mjbots::moteus::PositionMode::Command cmd;
    cmd.position = std::numeric_limits<double>::quiet_NaN();
    cmd.velocity = 2.0;  // 2 revolutions/second

    auto result = controller.SetPosition(cmd);
    ```

## Torque Control

For a pure torque control application, the PID gains of the position control loop must be set to 0.  One way to accomplish that is by sending the `kp_scale`, `kd_scale`, and `ilimit_scale` values to 0.

=== "Diagnostic Protocol"

    ```
    # Command a torque of 0.1 Nm
    d pos nan 0 nan p0 d0 i0 f0.1
    ```

=== "Python"

    ```python
    await controller.set_position(
        position=math.nan,
        velocity=0,
        kp_scale=0.0,
        kd_scale=0.0,
        ilimit_scale=0.0,
        feedforward_torque=0.1,
    )
    ```

=== "C++"

    ```cpp
    mjbots::moteus::Controller::Options options;
    options.position_format.kp_scale = mjbots::moteus::kFloat;
    options.position_format.kd_scale = mjbots::moteus::kFloat;
    options.position_format.ilimit_scale = mjbots::moteus::kFloat;
    options.position_format.feedforward_torque = mjbots::moteus::kFloat;

    mjbots::moteus::Controller controller(options);

    mjbots::moteus::PositionMode::Command cmd;
    cmd.position = std::numeric_limits<double>::quiet_NaN();
    cmd.velocity = 0.0;
    cmd.kp_scale = 0.0;
    cmd.kd_scale = 0.0;
    cmd.ilimit_scale = 0.0;
    cmd.feedforward_torque = 0.1;

    auto result = controller.SetPosition(cmd);
    ```

**Caveat**: Using external torque control will be much lower
bandwidth than using the internal position controller of moteus (~15x
lower bandwidth if maximal CAN-FD update rate is achieved).  Thus, a
system will usually perform better if as much of the desired control
law as possible is formulated in terms of the built in position
controller.

If the system will never perform anything *but* torque control, then the PID gains can be set to 0 in configuration.

* `servo.pid_position.kp`
* `servo.pid_position.kd`
* `servo.pid_position.ilimit`

## Jerk Limited Trajectories

moteus only supports acceleration limited internal trajectories.  To
approximate a constant jerk trajectory, the host processor should send
a sequence of piecewise linear constant velocity trajectories which
approximate the desired one.  This would be done by sending commands
consisting of at least a position and velocity at some moderate to
high rate while disabling the internal velocity and acceleration
limits.

## Low Speed or Precise Positioning

For either operation at very low speeds, or when precise positioning
performance is desired, it is recommended to configure a non-zero `ki`
and `ilimit` term in the position controller
([reference](../reference/configuration.md#servopid_position)).  This will compensate for cogging
torque (at the expense of overall torque bandwidth).  It may also be
beneficial to select a higher value for calibration bandwidth.

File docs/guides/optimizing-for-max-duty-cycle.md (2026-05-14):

# Optimizing for maximum duty cycle

## Background

In some cases, it is important that moteus be able to achieve the maximum possible speed on a given motor without resorting to field weakening.  The controller is limited in how much of the supply voltage it can apply to the motor.  By definition the multiple that it can supply is less than 1.  This multiple is constrained by moteus's requirement to be able to sense the current flowing to the motor in order to perform field oriented control. Two factors bound this constraint:

1. The current can only be sensed when the "low" side MOSFET is switched on.  Thus, the low-side MOSFET must be on long enough for ADC to trigger and complete its sampling process.
2. The input to the ADC is a current sense amplifier (CSA) onboad moteus.  This amplifier has a gain dependent settling time that must be respected.  This settling time must complete *before* the ADC sampling process starts.

## Tuning parameters

To maximize the available duty cycle, there are two parameters that can be controlled.

1. `servo.pwm_rate_hz`: The lower the PWM rate, the higher the available duty cycle.  Setting it to the minimum of 15000 Hz is the limit.  Lower PWM rates decrease the control update rate and decrease the peak power the board can support.

2. `drv8323.csa_gain`: The current sense amplifier gain, which can be one of [5, 10, 20, 40].  The default is 20.  Lowering this to 10 gives the maximum duty cycle benefit at the expense of increased current sense noise.  This will result in more audible noise from the system and lower available torque control bandwidth.

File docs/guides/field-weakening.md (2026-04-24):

# Field Weakening

## Background

moteus controllers are used to operate permanent magnet synchronous motors (PMSM).  In normal operation, the maximum no-load speed that can be achieved by a PMSM is determined by:

```
max_speed_hz = Kv * supply_voltage / 60
```

With moteus, there are two further constants that are multiplied in, the space vector modulation constant, and the maximum modulation factor constant.  As of 2026, these combine to roughly:

```
k_svpwm * k_maxmod ~= 0.8
max_speed_hz = k_svpwm * k_maxmod * Kv * supply_voltage / 60
```

This limit occurs because the controller can only apply torque when the supply voltage is greater than the back-EMF generated by the motor while it is in motion.  It is possible to apply current in the non-torque generating axis (the D axis) to reduce the effective back-EMF constant and thus increase the effective Kv constant.  This effect is called "field weakening".  The magnitude of this effect depends upon motor construction.  Typically, interior permanent magnet synchronous motors (IPMSM) are capable of relatively large amounts of field weakening at moderate power expenditure.  Most hobby and low-cost brushless motors are surface permanent magnet synchronous motors (SPMSM) for which field weakening is sometimes possible at reasonable power budget and sometimes not.

moteus has support for operating in the field weakening regime and thus extending the maximum achievable speed a motor can achieve for a given supply voltage.  This has several caveats:

- **Power**: The power required to operate a motor will be the same or larger when field weakening is enabled.  When field weakening is used, additional power will start to be used slightly before the no-load speed so that maximum torque can be achieved.  At higher speeds, the power consumed by the supply and dissipated as thermal energy in the motor and controller can be very large.  The amount used is also proportional to the maximum configured current, so if the full amount is not required for your application, lowering `servo.max_current_A` may be helpful.
- **Calibration**: Field weakening relies on the specific value of the D axis inductance.  For many motors, this value can change significantly at different values of D axis current.  In order to operate stably, moteus requires a longer calibration step to measure this D axis inductance saturation scale effect.
- **Stability**: For some motors, moteus must be calibrated at a higher `--cal-bw-hz` to operate at a speed in the field weakening regime than would be necessary if the supply voltage were high enough to not require field weakening.  Calibrating at a higher `--cal-bw-hz` will result in increased audible noise at all speeds.
- **Hardware Limits**: Even when field weakening is enabled, moteus will restrict the maximum speed to be no more than what could be achieved if the used moteus controller was supplied with its maximum rated input voltage.  Thus if you are already operating your controller near the maximum rated board voltage, there may be minimal or no gains in speed achievable through field weakening.

The [moteus performance analysis tool](https://mjbots.github.io/moteus/mpat.html) can be used to estimate the power required and performance when field weakening is enabled or disabled for a given system.

## Usage

Using field weakening with moteus requires calibration procedures and configuration values to be set.  Additionally, there are diagnostic values which can be monitored.

### Calibration

When calibrating, it is recommended to perform the D axis inductance scale procedure.

```
python -m moteus.moteus_tool -t 1 --calibrate --cal-measure-ld-saturation
```

This will require several minutes of operation and may require active cooling of the motor or controller in order to succeed.

The calibrated `L_d` scale will be nearly the same for all copies of a single motor design, so this parameter can be copied from controller to controller so that the calibration only needs to occur once across multiple instances.

```
servo.inductance_d_scale
```

### Configuration

To enable field weakening operation, use this configuration:

```
servo.fw.enable 1
servo.bemf_feedforward 1
```

`servo.bemf_feedforward` should be set to 1 when field weakening is used so that the controller can properly anticipate the back-EMF voltage and maintain stable operation at high speeds.

### Monitoring

When in operation, there are some diagnostic values that can be monitored:

`servo_stats.motor_base_velocity`: This is the speed at which field weakening begins.  Above this speed, additional power will be applied to the motor, increasing with speed, to enable operation above the no-load speed.

`servo_stats.motor_max_velocity`: This is the maximum speed moteus will permit.  Note that this is not a continuous rated speed, as temperature of the board or motor may rapidly exceed configured limits when operating at large levels of field weakening.

`servo_stats.fw.id_A`: The amount of D axis current currently being used to decrease the back EMF constant.

## Limitations

- **Board maximum voltage**: moteus limits field weakening speed such that the back EMF produced by the motor never exceeds `servo.max_voltage` minus an appropriate margin
- **Maximum D axis current**: `servo.fw.max_current_ratio` is multiplied by `servo.max_current_A` to determine the maximum D axis current that can be used for field weakening
- **Thermal performance**: Field weakening operates by applying *more* power to the motor.  This means it will increase in temperature faster, reducing thermal performance.

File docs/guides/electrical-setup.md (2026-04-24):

# Electrical Setup

To use moteus without damage, proper care must be paid to the electrical connections and configuration.  This section describes how.

## Electrical Connections

**Motor**: Phase wires for the motor should be soldered to the pads labeled A, B, and C. The order does not matter. The location of the pads varies between controllers.  An inline connector, like an MR30, MR60, or bullet connectors can be used if repeated disconnection is desired.

**Power**: Power is provided via either the onboard XT30 connector, or on board-mountable moteus controllers, via the power pads that are interleaved with the A, B, and C phase pads.  The power input is *NOT* protected against reverse polarity.  Polarity should be triple checked before applying power, or irreversible damage may result.  XT30 connectors have a clear '+' and '-' marking on them which can be used to identify the positive and negative input.

If you are unsure, pinout diagrams for all controllers can be found here: [Pinout diagrams](../reference/pinouts.md)

!!! note "Hot plugging"
    It is important to *never* hot plug an XT30 connector.  The XT30 connector (and all connectors which are not anti-spark), should be connected *before* power is applied.  If you see or hear a spark, you have applied power in the wrong order.  See the below section on inrush current management.

## Soldering and cable construction techniques

moteus controllers can be damaged when improper techniques are used to attach wires to them, or improper techniques are used to construct power cables.

### Phase Wire Soldering

The connections between moteus and the motor under control must be high quality.  Poor quality solder joints can cause intermittent changes in resistance, sparking, and high voltage transients.  High quality solder joints require:

* Sufficient flux to clean oxides off of the wire and the via
* Sufficient temperature so that the entire wire and via is hot enough for the solder to wet all surfaces

For the former, it is often necessary to add copious amounts of additional flux in addition to the rosin core inside many solders.  For the latter, a high power soldering iron, with a fat tip, and what seems like a long time may be necessary.  The temperature is definitely insufficient if solder touched to any part of the via or wire does not melt and wick instantly.  Usually a small amount of solder is placed between the tip and wire to act as a heat transfer agent.  Then the iron rests on the via and wire for between 5-30s until it looks like the initial solder has wicked fully into the via.  Then additional solder can be added until it forms a clean smooth fillet around the entire via wicking up to the wire.

When complete, the back side of the hole can be examined, and if successful, solder will have wicked partially down out of the via onto the other side forming a clean, smooth fillet there as well.

A demonstration of this can be found in the following video: [https://www.youtube.com/watch?v=mZ9w_TaWmjQ](https://www.youtube.com/watch?v=mZ9w_TaWmjQ)

{{ youtube("mZ9w_TaWmjQ") }}

### Power Cable Construction

When constructing power cables using XT30 connectors, it is critical that solder joints be sound, otherwise intermittent connectivity can result.  This can cause sparking and high voltage transients.  The soldering principles are the same as in the phase wire soldering section above.

A demonstration of XT30 soldering can be found in the following video:
[https://www.youtube.com/watch?v=f6WtDFWuxuQ](https://www.youtube.com/watch?v=f6WtDFWuxuQ)

{{ youtube("f6WtDFWuxuQ") }}

### Power Connectorization

For moteus to operate without damage, the XT30 connectors used to transmit power must make a solid connection that is non-intermittent.  As with poor soldering, an intermittent connection can cause inductive spikes, which will destroy components on the controller.

When connectors are functional, moderate insertion force should be required and the connectors should not "wiggle" much after insertion.

The XT30 is not rated for any significant amount of mechanical force when mated.  For any application where cables may flex, strain relief should be used such that no force is applied to the connector.  The connector may be damaged if a system goes "out of control" even in one instance, although milder mechanical stress may cause accelerated fatigue and failure.

If sparks are observed, that is *definitely* a problem and the system should be powered off until the connectors can be replaced and mitigations made for what led to that event.

Genuine AMASS connectors are rated for 1000 insertions assuming no other mechanical damage, however off-brand connectors may have worse tolerances and may not make a reliable connection for even one insertion.

### Long daisy chains

When connecting more than 3 moteus controllers or servos in a system on a single power or CAN chain, additional factors should be considered.

1. It is recommended to use T-spliced power instead of using the daisy chained power connectors for chains greater than 3 units.  Small connector mis-seating or micro-arcing will cause magnified effects with long chains of controllers.

2. CAN bus electrical performance can be a limiting factor.  To operate at the default 5Mbps, you will need to ensure that CAN wires are twisted, all crimps are high quality, and that termination is installed.  Split termination may be required, where two 60 ohm resistors are connected in series with a small filter capacitor connected between the center tap of the resistors and ground.  A 4.7nF capacitor is recommended.  If that is insufficient, BRS can be disabled to operate only at 1Mbps.  With `moteus_tool` or `tview`, the `--can-disable-brs` flag can be used.

mjbots sells a CAN terminator that can be used for this purpose: [https://mjbots.com/products/jst-ph3-can-fd-terminator](https://mjbots.com/products/jst-ph3-can-fd-terminator)

## Inrush current management

moteus controllers have large DC bulk capacitance with low ESR, this is how they can achieve their small form factor.  As a result, care must be taken when applying power.  If a connector is "hot-plugged" extremely large transient currents can develop which may damage the moteus or other components in the system.  These challenges are magnified when more than one moteus controller is attached to the same power bus.

Potential solutions:

**Power Supply**: If a wall power supply is used, it can be relied upon to provide a "soft start" functionality.  Ensure that all moteus controllers are attached to the power supply *before* enabling the supply by turning it on or plugging it into a wall.

**Anti-spark connectors**: There exist anti-spark connectors like the XT90-S, which have a power resistor built in which makes contact before main power is applied.  These can be used, but have several drawbacks:

1. The proper order of connection must always be obeyed.  Unless the XT90-S is connected *last*, then inrush transients may result.
2. If the power rating on the built-in resistor is not respected, it will silently fail, resulting in no pre-charge protection at all.

**Active pre-charge circuits**: mjbots sells the [mjpower-ss](https://mjbots.com/products/mjpower-ss) and [power_dist](https://mjbots.com/products/mjbots-power-dist-r4-5b), both of which have the primary function of gradually precharging capacitive loads.  Other active pre-charge systems may also be viable.

## Regenerative braking safety

moteus can be commanded to sharply decelerate loads, either directly in response to commands, or due to external disturbances.  When braking a load, moteus by default applies the generated power to the input DC bus.

If there is nowhere for this power to go, this can cause problems.  The voltage can increase without bound, which in mild cases will cause the CAN transceiver on all devices connected to the bus to fail, and in severe cases can explode the main FETs or other components on the board.

Here's what you should know about the facilities moteus has to deal with this, and what you can do to make your design safer.

### Software protections

moteus has several configurable mechanisms to limit regenerative voltage rise.  For full tuning details, see [Troubleshooting Overvoltage Fault 34](../troubleshooting/overvoltage-fault-34.md).

**Acceleration limits**: Setting `servo.default_accel_limit` (or per-command `accel_limit`) controls how quickly braking torque is applied.  This is the most direct way to limit the rate of regenerative power injection.

**Regen power limiting**: Setting `servo.max_regen_power_W` limits how much power is allowed to flow back to the bus during braking.  Excess energy is pre-emptively dissipated in the motor windings via d-axis current injection.  For a supply that cannot absorb any regenerative energy, set this to a small number like `10` or even `0`.

**Flux braking**: When bus voltage rises above `servo.max_voltage - servo.flux_brake_margin_voltage`, moteus dissipates energy in the motor windings to resist further voltage rise.  This is controlled by `servo.flux_brake_margin_voltage` and `servo.flux_brake_resistance_ohm`.

### Hardware design considerations

The following design considerations can be used to minimize the risk of damage to hardware in the event of overvoltage.  These are not a substitute for validation in progressively more demanding situations, but they can help you start off in a good place.

- *Tightly scope the over-voltage fault / flux braking*: The configuration parameter `servo.max_voltage` can be lowered for all devices on the bus.  This will both cause a fault if the voltage exceeds this value and in conjunction with `servo.flux_brake_margin_voltage`, select the point at which moteus will attempt to dissipate energy to prevent an overvoltage scenario.  It is recommended to set this to no less than 5V above the maximum expected supply voltage.

- *Power from a battery, not a PSU*: When not charged, batteries are capable of sinking current to minimize over-voltage transients.  However, if the battery is fully charged, most battery management systems drastically reduce the allowable charging current.  Thus, a battery is only useful as a mitigation if it is never charged above say 75 or 80% state of charge.

- *Decrease overall system voltage*: If you run the moteus controller with say a 10S battery, the peak input voltage can be as high as 42V.  That does not leave very much margin for regenerative loads.  For applications that experience sharp regenerative loads and do not have a battery capable of charging always attached, it is recommended not to exceed 8S (33.6V peak).

- *Use a supply which can sink as well as source*: Powering from an inexpensive lab supply is the most dangerous, as they typically have no ability to sink current, only source it.  A "two quadrant" supply is the necessary device.

## Next Steps

After completing electrical connections, proceed to [software installation and configuration](software-installation.md) to begin using your moteus controller.

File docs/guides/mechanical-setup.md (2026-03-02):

# Mechanical Setup

To use the onboard on-axis encoder integrated with moteus, the controller must be mounted with care to ensure proper alignment and ongoing registration.

## Mechanical Mounting

If using the default onboard encoder, the following steps must be taken:

1. A diametrically magnetized sense magnet should be attached to the rotor (*NOT* the output of any reducer or linkage). The fastening must be rigid, allowing no slip. Adhesive is generally required, cyanoacrylate or epoxy can be used.
2. The moteus controller must be mounted so that the encoder is (a) centered laterally on the sense magnet and (b) has an air-gap of approximately 2mm. This mount must be rigid and allow no slip.

!!! note "moteus-r4 mounting"
    Unlike other moteus controllers, the moteus-r4 encoder is *not* centered under the bolt pattern, check the [2D CAD for details](https://github.com/mjbots/moteus/blob/main/hw/controller/r4.5/20210124-moteus-controller-r45-mechanical.pdf).

!!! note "3D printed mounts"
    If using 3D printed mounts, care should be taken to ensure the mount does not warp.  PLA and other low temperature filaments will warp under load at room temperature, and will do so even more when exposed to thermal heating like from a motor controller.  It is recommended to use PETG, PC, or a filament designed to not warp at the operating temperature you intend.

## Additional Considerations

There are additional considerations when mounting, some mostly common sense, and some unique to moteus.

### Protection from debris and stray conductors

It is advisable to mechanically shield moteus controllers from the environment during operation to prevent contact with stray conductors, dirt, or debris.  Contact with any of these things while the system is energized can result in failure.

Similarly, manipulating or working on the system while it is energized should be avoided.

### moteus-n1 light sensitivity

moteus-n1 has a voltage regulator which is light sensitive and will fail when exposed to sunlight.  The enclosure used to house the system should be opaque.  If for some reason an enclosure can not be used, opaque expoxy can be placed over the voltage regulator IC.

moteus-c1, moteus-r4 and moteus-x1 have no light sensitivity considerations to take into account.

## Next Steps

Once mechanical mounting is complete, proceed to [Electrical Setup](electrical-setup.md) to connect the motor phase wires and power.

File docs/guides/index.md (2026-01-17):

# Using moteus

Step-by-step guides for setting up and using moteus.

- [Mechanical Setup](mechanical-setup.md) - Physical installation
- [Electrical Setup](electrical-setup.md) - Wiring and power connections
- [Software Installation](software-installation.md) - Installing client software
- [Configuration](configuration.md) - Basic configuration
- [Encoder Overview](encoder-overview.md) - Understanding encoder options
- [Calibration](calibration.md) - Motor calibration procedure
- [PID Tuning](pid-tuning.md) - Tuning position and velocity control
- [Control Modes](control-modes.md) - Position, velocity, and torque modes

## Advanced Configuration

- [Motor with Hall Effects](hall-effects.md) - Using hall effect sensors
- [Dual Encoders](dual-encoders.md) - Separate motor and output encoders

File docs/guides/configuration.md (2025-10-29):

# Configuration

Before using a moteus controller for the first time, it is necessary to configure several key parameters. These parameters define operational limits, control behavior, and configure the system to match your specific application.

## Essential Configuration Parameters

The following parameters should be reviewed and will likely need to configured in a customized way for nearly every application.

### Position Limits

**`servopos.position_min` and `servopos.position_max`**

These define the bounds of motion which the controller will allow when in position control mode. Attempting to start beyond this region will fault, and if outside the region during operation, no torque will be applied to move further outside these limits.  If they are unwanted, `nan` should be used to disable them.

### Current Limits

**`servo.max_current_A`**

The maximum phase current to apply to the motor. This can be used to limit the maximum torque that the system is capable of producing, regardless of any command sent. Set this based on your motor's peak current rating and thermal capabilities.

### Velocity Limits

**`servo.max_velocity`**

Limits the maximum speed the motor is permitted to achieve before no torque is produced. This acts as a safety limit to prevent excessive speeds that could damage the motor or mechanical system.

**`servo.default_velocity_limit` / `servo.default_accel_limit`**

Controls how fast the motor can accelerate and spin in order to reach position and velocity targets. Bare boards ship with these unset, while development kits ship with human-eye pleasing values. Adjust these to match your application's performance requirements.

### Gearbox Scaling

**`motor_position.rotor_to_output_ratio`**

A gearbox scaling factor. A reducing gearbox should be configured with a number smaller than one (e.g., 0.25 for a 4x reduction gearbox). This affects reported position, speed, and torques, scaling them to represent the output shaft values rather than motor shaft values.

### Device Identification

**`id.id`**

The CAN-FD ID used by this device. Each controller on the bus must have a unique ID. Valid IDs range from 1 to 126.  If you set this to a value other than 1, be aware that unless your tview and controller firmware are newer than late 2025, you will need to restart tview with:

```
python -m moteus_gui.tview -t N
```

Where N is the new ID, in order to issue a `conf write` to save the
parameters.

### PID Parameters

**`servo.pid_position`**

The PID parameters for the position control loop. It will be necessary to tune these, it isn't hard, although it must be done after calibration is performed. You'll get to the [PID Tuning guide](../guides/pid-tuning.md) after completing the calibration process.

## Saving parameters

All parameters (including the ID) are temporarily stored in volatile memory that will be discarded after a power cycle.  To save those parameters to persistent storage, it is necessary to type:

```
conf write
```

Into the diagnostic console of tview.

## Additional Configuration

A larger set of parameters is documented in the [Configuration Parameters Reference](../reference/configuration.md), covering advanced features such as:

- Motor electrical characteristics
- Encoder configuration
- Temperature limits
- Communication settings
- Advanced control parameters

## Next Steps

After configuring these essential parameters, you should familiarize yourself with the encoder system and position feedback:

- [Encoder Overview](encoder-overview.md)

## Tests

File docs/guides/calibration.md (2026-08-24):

# Calibration

If you started from a bare moteus board, you will need to calibrate it for the attached motor before any control modes are possible. Calibration is required when:

- Using a new bare moteus controller for the first time
- Changing to a different motor
- Altering the mechanical registration between the controller and motor
- After certain configuration changes that affect motor characteristics

Development kits typically come pre-calibrated and do not require this step unless the motor is changed.

## Calibration Command

To calibrate your moteus controller, run the following command:

```bash
python3 -m moteus.moteus_tool --target 1 --calibrate
```

Replace `1` with the appropriate CAN-FD ID if you have configured your controller to use a different ID.

## Important Safety Warning

**WARNING: Any attached motor must be able to spin freely during calibration.**

During the calibration process:

- The motor will be spun in both directions
- The motor will reach high speeds
- Ensure no mechanical obstructions are present
- Do not apply any load to the motor shaft
- Keep hands and objects clear of the motor and any attached mechanisms

The calibration procedure measures motor electrical characteristics and encoder alignment, which requires unrestricted motor motion.

## Alternate calibration parameters

### Limited rotation

The amount of motion required for calibration can be reduced if the Kv of the motor is known in advance.  In that case, specify as an additional command line argument:

`--cal-force-kv X`

Where X is the Kv of the motor.  In this mode, moteus will only spin the rotor 360 degrees in each direction and will not perform a high speed movement.

### Very small or very large motors

During the encoder calibration process, moteus applies a constant power to the motor.  The default power, 7.5W is sufficient for many motors but not all.  If the motor is very small, it could overheat or burn if applying that much power.  If the motor is very large, 7.5W may not be enough to cause the motor to move.  This can be altered by specifying:

`--cal-motor-power X`

Where X is the power in watts to apply.  Small motors will need smaller values, large motors may need larger ones.

### Updating encoder and torque bandwidth

If your application requires changing torque or velocity very quickly there are several additional considerations.

**Torque bandwidth**: You may want to configure an alternate "bandwidth" parameter during the calibration process.  The specific value of bandwidth can be roughly used to estimate how quickly moteus can change the output torque, and how quickly it can sense velocity and position changes.  For instance, the default bandwidth is 200Hz.  This means that as a rough order of magnitude, moteus can change the torque or observe a change in velocity in 1/200 = 5ms.  Higher bandwidth values will result in the controller and motor emitting more audible noise.  Other than audible noise (which can be significant), there is not much downside to increasing the bandwidth.

`--cal-bw-hz X`

**`servo.max_current_desired_rate`**: moteus limits the rate at which the commanded phase current to the motor can change.  By default, this is set to 10000A/s.  For a moteus-r4 with a 100A current limit, that means it can take 20ms to change full range from -100A to 100A.  Many high bandwidth applications will require rates larger than this.

## Troubleshooting

If you encounter issues during calibration, such as:

- Motor not spinning
- Calibration failures or errors
- Unexpected motor behavior

Refer to the [Troubleshooting Guide](../troubleshooting/calibration.md) for common problems and solutions.

## Next Steps

After successful calibration, you can conduct the PID tuning process:

- [PID Tuning](../guides/pid-tuning.md)

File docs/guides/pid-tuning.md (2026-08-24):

# PID Tuning

When operating in position or velocity mode, moteus uses a P(I)D controller to determine what torque to apply at each instant.  The constants that control this operation need to be selected by the user.  Tuning does not have to be challenging, but does require that you understand what you are trying to accomplish.

## Theory

The purpose of the three gains:

**Proportional**: This term applies a restorative torque that is proportional to the error between the current desired position and the current measured position.  It is measured in Nm per revolution of error as measured at the output of the reducer.  It directly controls the "stiffness" of the controller.  If used in isolation, the motor will apply a fixed torque for any given error, i.e. if you manually move the motor 0.1 revolution away from the setpoint, it will apply 0.1 * the torque indefinitely, and then if you move it to be 0.2 revolution away from the setpoint, it will apply 0.2 * the torque.

**Derivative**: This term acts as a "damping" term, or viscious resistance.  As an analogy, if the proportional term is the spring in a suspension system, the derivative term is how thick the oil in the suspension is.  The torque applied from this term scales with the magnitude of the error between the desired velocity and the measured velocity.  If all other gains were zero and the motor is disturbed by hand, a larger gain makes it feel like you are working against a thicker fluid resistance.

**Integrative**:  The integrative term applies a torque that scales with the error in position integrated over time.  Many, if not most, moteus systems use no integrative term at all.  Integrative terms are hard to tune, and result in poor transient response.  However, they are the only way to achieve 0 steady state error in a loaded system.  Without an integrative term, the steady state error, while possibly very small, will never be zero.  For the integrative term there are two parameters to select, the gain itself, and the anti-windup gain term.

## Procedure

The position control P(I)D loop parameters are set in `servo.pid_position` and are selected by the user to achieve a desired control response.  Most users want a PID controller that is well damped and sufficiently stiff for their application.

Here is a possible procedure for tuning.  It is best executed using tview in a configuration where you can move the motor with your hand.  A load that is close to representative in terms of inertia, damping, and friction is best, but something is better than nothing.

1. Set kp to be small and kd, ki, and ilimit to be 0.
```
servo.pid_position.kp = 0.001
servo.pid_position.kd = 0
servo.pid_position.ki = 0
servo.pid_position.ilimit = 0
```
If you have an understanding of the system, you could select an initial kp that is larger, but you want it to be a value such that the restorative torque is very gradual and you can easily disturb the system by hand.
2. Increase kp by 50% at a time until the desired stiffness is reached.
    1. Test the current value.  A command like `d pos nan 0 nan` can be used to "hold position".  Then use your hand to move the rotor to judge the stiffness.
    2. If insufficiently stiff, increase `servo.pid_position.kp` by 50% and go back to (a)
    3. If vibration or instability results, decrease `servo.pid_position.kp` by 2x and that is roughly a good stable maximum.
3. Tune the derivative term
    1. Set kd initially to 1/100th of the kp value. For example, the following where FOO is 0.01 * the selected value for `servo.pid_position.kp`.
`servo.pid_position.kd = FOO`
    2. Test the current value.  Use `d pos nan 0 nan` to hold position.  Manually move the motor away from the setpoint, then quickly release it.  If "damped" the motor will smoothly come to a stop at the original position.  If underdamped, the motor may oscillate.
    3. If insufficiently damped, increase `servo.pid_position.kd` by 50% and go back to (a)
    4. If high frequency vibration or oscillation results, decrease `servo.pid_position.kd` by 2x and that is roughly a good stable maximum.
4. If zero steady state error is required, then an integrative term is required.  If not, leave `ilimit` at 0 and you are done.
5. Configure the integrative term.
    1. Set `servo.pid_position.ilimit` to be 20% higher than the maximum expected steady state torque.
    2. Set an initial value of `servo.pid_position.ki` equal to the `servo.pid_position.kp` term.
    3. Increase `servo.pid_position.ki` until the desired response is achieved.  `ki` will likely need to be numerically much larger than kp, on the order of 10-1000x larger.  A more representative control profile than just a "hold position" may be needed to determine if the selected integrative constants are sufficient.

## Acceleration limited trajectories

Further, it is *strongly* recommended to configure and use an acceleration limit with moteus that is physically achievable in your system.  Doing so means that the "desired" position and "desired" velocity will follow continuous, physically achievable trajectories.

- `servo.default_accel_limit` can be set in Hz / s.

If you do not set an acceleration limit, or select one that is too high to be physically achievable, your system will experience overshoot during movements and you will find it challenging to tune the P(I)D parameters to achieve a desired response.

## What not to tune

The "current loop" bandwidth is set in `servo.pid_dq_hz`, and the
gains are computed automatically from it and the calibrated motor
parameters.  It is not normally changed by the user directly.
Instead, it is selected by specifying an appropriate `--cal-bw-hz`
during calibration.

## Next steps

Now you are ready to control moteus using one of the possible control modes:

- [Control](../guides/control-modes.md)

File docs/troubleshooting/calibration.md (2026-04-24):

# Troubleshooting Calibration

When setting up a [moteus controller](https://mjbots.com) with a new motor, you typically first run the automatic calibration sequence as [documented in the reference manual](../guides/calibration.md). When your system is working well, that should be all that is necessary to enable moteus to perform accurate FOC based torque control of the motor. Then you can continue on with the remainder of the items in the [Quick Start](../quick-start.md). What happens though when the automatic calibration doesn't work? This article describes the most common failure modes during calibration.

Unfortunately, most calibration failures present the same final symptom, an error like:

```
CAL timeout
```

or

```
encoder not an integral multiple of phase
```

So to resolve, you typically start with the first items in this article, then work your way down to the less common ones.

## Sense magnet issues

To operate properly using the onboard encoder, moteus requires that a diametrically magnetized sense magnet be rigidly affixed to the rotor, that it be centered laterally under the magnetic encoder on moteus, and that it has an appropriate air-gap. Let's look at each of those in turn.

First, you need a [diametrically magnetized magnet](https://www.kjmagnetics.com/magdir.asp). This is one where the axis of magnetization is sideways, so that the north pole points out of the curved side of the disc. This is contrast to axially magnetized magnets where the axis of magnetization points out of the flat side. There are a wide variety of possible options here. Every moteus controller sold at [mjbots.com](https://mjbots.com) includes an appropriate magnet, and [mjbots.com also sells spares](https://mjbots.com/products/d42dia). There are also suppliers with higher temperature magnets, like the [Radial Magnets, Inc. 9049 here at digikey](https://www.digikey.com/en/products/detail/radial-magnets-inc/9049/6030786). Sometimes however, you are converting an existing actuator to use moteus, and there is a sense magnet present already. The bad news is that it may or may not be usable with moteus and unless you know the specifications, it may be hard to know the optimal air gap required for it. In those cases it is often easiest to remove the existing magnet and replace it with a known quantity, especially if a reasonable air gap is hard to achieve.

Second, the magnet must be rigidly affixed to the rotor. No slipping is permitted whatsoever. Practically, that means that adhesive will be required at each junction between the magnet and the rotor. Common adhesives used are cyanoacrylate gel (superglue), and epoxy. For instance, if a 3D printed spacer is used, the magnet must be glued to the spacer, and the spacer must be glued to the rotor. When the rotor moves, the magnet must move. Press fits can be problematic unless the fit is designed with a well specified tolerance and relying on friction between a magnet and something it is attracted to will definitely not work.

Third, the magnet must be positioned laterally properly. This means that it needs to be centered under the magnetic encoder. For all moteus controllers but the moteus-r4, this is centered under the bolt pattern. For [moteus-r4](https://mjbots.com/products/moteus-r4-11), you should [look at the 2D CAD](https://github.com/mjbots/moteus/blob/main/hw/controller/r4.5/20210124-moteus-controller-r45-mechanical.pdf) to see where to position the magnet.

The magnet also needs an appropriate air gap between the surface of the magnet and the surface of the encoder IC. For the magnets that mjbots sells, 2mm is near the optimal air gap, with a range of 1.5mm - 2.5mm being suitable. Spacing of 0.5mm - 8mm will likely work with degraded performance.

Finally, the controller needs itself to be rigidly mounted with respect to the stator and rotor. If it is allowed to move or rotate, then the sensed angle of the rotor will not match the actual electrical angle needed for commutation, as well as degrading the quality of position control at the output.

## Electrical problems

The most common electrical problem that prevents calibration is poor or non-existent phase wire soldering. The phase wires of the motor must make a good connection to the moteus phase terminals. That means that when soldering, the joint must have reached a sufficient temperature and had sufficient flux such that the solder wicked both all around the wire, and wicked in to the phase wire terminal. Cold solder joints may show solder that does not fill the joint completely and does not form a proper fillet to the surfaces it touches or may show as visual artifacts between the wire, pad, and solder. This may result in no or an intermittent connection. A video showing what an appropriate result should look like is here:

{{ youtube("mZ9w_TaWmjQ") }}

The next most common electrical problem is a motor that is fundamentally broken. That could be one which has shorted phases, inappropriate polarity of windings, or magnets with inappropriate polarity. These problems usually only appear with second hand motors, those of low quality, or hand-built motors. The easiest way to rule it out is to test with a known working motor.

## Less Common Sense Magnet Issues

I have observed a few less common problems associated with sense magnets.

In one case, the magnet was actually glued both to the rotor and to a stationary mounting bracket, preventing the rotor from moving at all.

In other cases, magnets were allowed to exceed their rated operating temperature. The [magnets included with the moteus-r4, moteus-n1, and moteus-c1](https://mjbots.com/products/diametric-disc-magnet?variant=44912247013537) are rated to 70C.  If that is an issue, then magnets can be procured with higher rated temperatures, such as the [140C one from mjbots which is included with the moteus-x1](https://mjbots.com/products/diametric-disc-magnet?variant=44912246751393).

Sense magnets for commutation must be rigidly affixed to the rotor, \*not\* to the output of a reducer, or any linkage that may have backlash. If the magnet is attached to a reducer, then the required angular accuracy can easily exceed what the onboard encoder is capable of measuring. Linkages with backlash have the same problem.

## Mechanical Problems

If your rotor is not free to move, or has a significant load on it, then calibration can fail. Calibration will work with many kinds of reducers attached, but eventually the friction and stiction will be more than the process can manage. In some cases you can increase the power used during the lock-in phase of calibration by passing an extra option to `moteus_tool --calibrate`:

```
--cal-motor-power 5
```

The units are watts, and 5 is the default. You can increase this, but at higher values, you may run the risk of overheating your motor during the encoder calibration process.

If a suitable power cannot be found, then it may be required to design the motor and controller as a sub-assembly which can be first calibrated and then attached to the reducer.

## The bad news

The bad news is that the error checking in the calibration process is not foolproof. i.e. it is possible for a setup that is broken to still report that calibration completed successfully. The two biggest indicators that it did not actually work are that the Kv value reported during calibration is grossly incorrect or that position or torque control do not work reliably. If either of those happen, you need to work through the above potential causes and rule them out one by one.

## The good news

The good news is that if you have a working motor, an appropriate magnet, the magnet is rigidly affixed to the rotor and positioned properly, and your phase wire soldering followed proper technique, calibration should succeed virtually 100% of the time.

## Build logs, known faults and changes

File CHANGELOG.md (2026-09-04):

# Changelog

This file tracks notable changes per shipped component. Each component is
released independently; see [RELEASING.md](RELEASING.md) for the process.

The format is loosely based on [Keep a Changelog](https://keepachangelog.com/).

Entries are added under a component's `### Unreleased` heading by the
change that introduces them; cutting a release only renames that
heading to the version and date.

## firmware

### Unreleased

(no entries yet)

### 1.1.1 - 2026-08-04

- Change the default gate drive strength for moteus-n1 to the values which it was qualified at.  When the moteus-c1 was introduced, the moteus-n1 was accidentally set to more aggressive gate drive strength values.  This could result in increased gate drive failure rates with poor phase wire soldering or input voltages above 36V.
- Improve hall effect performance
  - Reduce velocity ripple by not starting the velocity decay process until *after* the expected transition
  - Improve velocity estimation when hall rising and falling times are mismatched
- Fix AksIM-2 wrapping on startup
- CUI AMT21: Actually operate the RS485 bus in half-duplex mode.  Previously, transmit was always asserted, which would occasionally sometimes work, but resulted in two masters on the bus at the same time.
- Improve I2C aux port robustness
  - Reset peripherals that are unresponsive
  - Enable the STM32 analog filter
  - Disable the STM32 own address matching feature
- Fix the location of the default UART port for moteus-c1 and moteus-n1.  The location of the UART port by default for all controllers now matches the documentation:
  - moteus-r4: AUX2/ABS
  - moteus-n1: AUX1
  - moteus-c1: AUX2
  - moteus-x1: AUX1

### 1.1.0 - 2026-08-04

Erroneous release with no changelog

### 1.0.0 - 2026-05-28

#### Firmware improvements

- Use a CSA gain based kCurrentSampleTime - this reduces the effective modulation depth in all configurations, more with the default CSA gain, but is actually correct and does not result in spurious current sense noise at high duty cycles no matter what CSA gain is configured
- Actually count errors if hall sensors flip more than one bit at a time
- Fix the used bitrate for I2C2, which affects I2C on aux2.  Previously, actual operation was at half the configured bitrate.
- When targetting a near-zero speed with an acceleration limit, in some cases we could oscillate.  Fix this to reach the target without oscillation.
- Force a hall sensor update on boot, if we otherwise got unlucky, a hall configuration could report no encoder configured
- For hall sensors, if our "slow velocity" heuristic coasts to the end of a sector, but then no more hall updates arrive, gradually recenter back to the center of the sector

#### Other firmware behavior changes

- Fix various undefined behaviors and assertions in the firmware that could be triggered by misconfiguration.

#### Utilities and examples

- `utils/measure_ma732_bct.py` is more likely to work if Y axis trimming is required.
- `utils/measure_inertia.py` has improved accuracy
- Various compensation scripts could fail if encoder values were unfortunately situated relative to the pi/-pi boundary
- `utils/plot_highrate.py` accepts hex / oct / bin literals for --emit-debug
- `lib/python/examples/ruckig_multiservo.py` both works properly on Windows and reports the mode and fault for each device

#### Release engineering

- First semver release, ABI bumped to 0x010000 (1.0.0), although no functional ABI changes were made.
- Implement a ubsan build, verify it in CI.
- Support building on Ubuntu 26.04

## python

### Unreleased

- moteus_tool now reports hall effect performance in the calibration report

### 1.1.2 - 2026-08-04

- Improve hall effect calibration
  - Fine calibration of hall transition point within the electrical cycle
  - Sweep through 3 electrical cycles in forward and reverse direction
  - If a hall sensor transition happens to be right on a sample point and oscillates, do something reasonable
- Support firmware ABI 1.1.0

### 1.1.1 - 2026-08-04

Unreleased version

### 1.1.0 - 2026-08-04

Erroneous release with no changelog

### 1.0.0 - 2026-05-28

#### Improvements

- `moteus_tool --calibrate` for controllers configured for hall commutation now calibrate a fine position for each hall transition, which improves performance and consistency for hall based configurations

#### Fixes

- `moteus.move_to` now respects the `velocity_limit` argument across all devices
- `moteus.move_to` works properly when exiting the stopped state
- Don't inject `await` when it isn't needed, rending some python mode definitions possible that previously would have triggered syntax errors
- Fix the order of D and Q axes for current mode requests

## cpp

### Unreleased

(no entries yet)

### 1.0.0 - 2026-05-28

* First semver based release.

## rust

The `moteus`, `moteus-protocol`, and `moteus-derive` crates share one
version and are released together.

### Unreleased

### 0.5.5 - 2026-09-04

- Integer transport arguments accept negative values, so
  `--pi3hat-cpu -1` works as a bare argument (previously only
  `--pi3hat-cpu=-1` or `none` did).

### 0.5.4 - 2026-09-04

#### Improvements

- The examples accept transport-specific arguments and report those in
  help messages.
- New `transport::args::parse_with_transport_args::<T>()`: parses a
  clap derive struct together with every registered transport
  argument.
- The `bandwidth_test` example uses the synchronous transport.
- docs.rs renders the feature-gated API (async transports, clap
  helpers).
- The bazel crate specifications are exported from
  `lib/rust/crates.bzl` for downstream workspaces.

#### Fixes

- The crates build on their declared MSRV of 1.75 again (0.5.3 used
  `Option::is_none_or`, which needs 1.82). CI now checks the MSRV.
- `TransportOptions::from_arg_matches()` no longer panics when the
  command defines only a subset of the transport arguments.

#### Behavior changes

- `dispatch_frame` never delivers replies to requests that do not
  expect one.
- `create_transports` / `create_async_transports` actually report
  failure error messages to callers.

### 0.5.3 - 2026-06-17

- The example bodies are exposed as a library via the `examples`
  feature, so downstream binaries can reuse them with other
  transports.
- `ArgSpec::new()` lets external transport factories declare
  command-line arguments.

### 0.5.2 - 2026-06-17

- Re-release; no library changes.

### 0.5.1 - 2026-06-17

- Support out-of-crate transports: parent-only transport devices and
  `known_can_ids` routing hints.
- Support moteus connected directly over TTL-level UART.
- Examples moved into the crate.

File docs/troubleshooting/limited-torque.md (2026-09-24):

# Troubleshooting Limited Torque

If moteus is able to control a motor, but is unable produce sufficient torque for your application's needs, this post describes diagnostic steps.

## Outline

There are a few main classes of things that can limit torque.

1. **Misconfiguration**:  Things that fall into this category include PID constants that are not tuned or an overly aggressive current limit or thermal limit.
2. **Under-cooled controller or motor**: If the controller and motor are properly sized for the application, they may still require thermal management to achieve those goals.
3. **Under-sized controller or motor**: If thermal management alone is insufficient, or is not practical, then either a larger controller or larger motor may be required.
4. **Insufficient supply voltage**: With low-Kv motors, it is possible for supply voltage to be a limiting factor.

## Diagnosing

First you need to understand which of the above three classes you are in.  To do so, there are some possible diagnostics and other things to check.

### Output Limit Reasons

As of firmware version 2025-07-21, the firmware will report if a factor is limiting the output current via the "fault" register while in position mode.  The set of possible values are:

- **96 max_velocity**: Maximum velocity: If the observed velocity exceeds the configured maximum velocity, torque is limited in the direction that would cause the velocity to increase.  This is configured with `servo.max_velocity`.
- **97 max_power**: Maximum power: The total power of the output is limited through a combination of a board power profile and `servo.max_power_W`.  [See this post for more](https://blog.mjbots.com/2025/03/29/moaar-power/).
- **98 BEMF**: Maximum system voltage: The supply voltage, combined with the back EMF of the motor and the phase resistance does not permit more current to be applied.
- **99 max_current**: Maximum current: There is a system wide maximum output phase current that is configured in `servo.max_current_A`.
- **100 fault_temperature**:  Temperature: The onboard FET temperature sensor can limit the output current.  This threshold is set in the current firmware with `servo.fault_temperature`/`servo.temperature_margin`.
- **101 motor_temperature**: Temperature: The motor temperature sensor can also limit the output current.  This is configured in `servo.motor_fault_temperature`/`servo.motor_temperature_margin`.
- **102 max_torque**: Maximum torque: With each position mode command, the client can specify a maximum torque to use.  If the combination of the onboard PID and commanded feedforward torque exceeds this, then limiting occurs.
- **103 position_bounds**: Position bounds: If the current position is outside of `servopos.position_min` and `servopos.position_max`, then torque is limited in the direction that would push the motor further outside the bounds.
- **104 flux_braking**: Flux braking: The input voltage is too high and the controller is dissipating energy in the motor windings.
- **105 field_weakening**: Field weakening: The motor is above its base speed, so the controller is applying negative D axis current to reach the commanded speed, which reduces the torque available.  This is configured with `servo.fw.enable` and related `servo.fw.*` parameters.

### Other possibilities

If none of the above limiting flags are present, then the remaining options include:

#### Not stiff enough PID tuning

The torque applied by moteus (aside from any feedforward torque), is determined by the error between the desired and measured position and the error between the desired and measured velocity.  If the constants controlling this process are too low, then moteus will apply very little torque even for large errors.

One common way this occurs with moteus is:

1. A PID tuning is created
2. Later, a reducer is configured using `motor_position.rotor_to_output_ratio`
3. Wow, now moteus doesn't output much torque

The important point to note here is that the PID terms for the moteus control loop are measured at the *output* of any reducer.  Thus if kp=1, that means apply 1Nm of torque *at the output* for 1 revolution of error *at the output*.  With a reducer, that means the effective gains at the rotor are reduced by the reduction squared.

So, after configuring a reducer, you can either re-tune the PID gains, or increase the gains by the square of the reduction.

Sample:

```
servo.pid_position.kp = 4
servo.pid_position.kd = 0.05
motor_position.rotor_to_output_ratio = 1
```

You test this and it works great.  Then you configure the 8x reducer which was always present.

```
motor_position.rotor_to_output_ratio = 0.125
```

And now all of a sudden the controller barely does anything at all.
To have equivalent stiffness, you now need to increase the kp and kd
gains by a factor of `8 ** 2 = 64`.

```
servo.pid_position.kp = 256
servo.pid_position.kd = 3.2
```

#### Invalidated calibration

If your calibration was invalidated, it can result in lack of torque.  Invalidation can happen for any of the reasons in the [calibration troubleshooting guide](calibration.md), and include:

- A sense magnet that was not rigidly affixed to the rotor, say because adhesive not used at a joint
- A sense magnet that exceeded its rated temperature
- The controller mounting shifted

To test these hypotheses, re-calibrate the motor and check again.  If
the problem is resolved, then you need to identify which of the above
issues was the most likely culprit and resolve it.

#### Other "limiting like things"

There are some "limiting-like" features that do not report through the
fault code mechanism.  If position bounds are configured, the control
position is limited to stay within those bounds.  This does not
directly limit torque, so is not reported via this mechanism.

Similarly, if the commanded velocity exceeds either the velocity
limit, `velocity.max_velocity`, or `servo_stats.motor_max_velocity`,
then it is truncated to stay within.  These limits are not reported
via the fault code mechanism.

## Resolution

If the error was mis-configuration, fix it and you are done.

If the error was not mis-configuration, then the resolution depends upon what was causing the limiting.

### Thermal limiting

If the limit was thermal, then your options are:

1. apply cooling to whatever was hot
2. use a bigger controller or motor for whatever was hot
3. use a reducer, or if already using a reducer, use a bigger one

### Maximum current

If you hit the controller maximum current limit, then your options are:

1. use a different motor
2. use a controller with a higher current limit
3. use a reducer, or if already using a reducer, use a bigger one

### BEMF or `servo_stats.motor_max_velocity`

If you are limited by the back EMF of your motor, then your options are:

1. use a higher supply voltage
2. use a different motor with a higher Kv rating

### max power

Here, your options are:

1. configure a higher PWM frequency
2. use a bigger controller
3. use a different motor
4. use a reducer, or if already using a reducer, use a bigger one

## Resolution caveats

### Reducers

If considering using a reducer or a bigger reducer, the biggest caveat is that the maximum speed will be decreased by a corresponding amount.

Secondarily, most reducers have backlash and will add static and dynamic friction to your system and may have limits on maximum torque or speed that become limiters.

### PWM frequency

If increasing the PWM frequency to improve peak power, this will also decrease the efficiency of moteus.  That will result in lower continuous output current and power ratings.

### Cooling

The obvious downsides of cooling are noise, lower reliability, and increased power consumption even when under no load.

## moteus performance analysis tool

If attempting to design a motor system to achieve a particular goal, it may be useful to use the moteus performance analysis too, which lets you vary these parameters and measure the resulting performance of the system.

- [https://mjbots.github.io/moteus/mpat.html](https://mjbots.github.io/moteus/mpat.html)
- [mpat blog post](https://blog.mjbots.com/2025/07/17/moteus-performance-analysis-tool-v2/)

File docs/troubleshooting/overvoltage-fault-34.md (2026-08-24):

# Troubleshooting Overvoltage Fault 34

moteus brushless motor controllers both apply power to motors and, depending upon the mode and external system state, can act as a generator, often termed regenerative braking.  When acting as a generator energy is emitted to the input DC bus -- this causes the voltage to rise at a rate depending upon the characteristics of the supply.  If the voltage rises far enough and for a sufficient time to trigger it, [flux braking](../guides/electrical-setup.md#flux-braking) may cause some energy to be expended in the windings of the motor.  If the regenerative braking energy increases rapidly, or is larger than the configured flux braking can dissipate, the voltage can rise above the configured fault voltage in `servo.max_voltage`, which will trigger a fault.

If you are seeing fault 34 in your application, there are several largely independent methods that can be attempted to resolve the problem.

## Configuring acceleration limits

For flux braking to operate, the rate at which regenerative power increases must be limited.  The easiest way to do so is to use acceleration limits that are as low as your application can tolerate.  The default acceleration limit can be set with the configurable parameter:

```
servo.default_accel_limit
```

Or the limit can be sent with individual position mode commands.

If you don't know what acceleration is appropriate, you can either:

- use back of the envelope calculations of the form, "I know the system needs to change from velocity X Hz to velocity Y Hz in Z s, thus the acceleration is (Y - X) / Z"
- select a large acceleration limit that is unlikely to cause problems, say 10000Hz/s.  Then lower it progressively until your application has issues.  Select a final value a healthy margin above where the issues started.

## Limit regenerated power with `servo.max_regen_power_W`

When generating power, by default moteus sends all of this energy back to the DC bus.  This can cause the voltage to rise if the supply has non-trivial impedance.  By setting `servo.max_regen_power_W`, you can limit how much regenerated power is allowed to flow back to the bus.  Any excess is pre-emptively dissipated in the motor windings by injecting d-axis current.

For example, to allow no more than 50 watts of regeneration:

```
conf set servo.max_regen_power_W 50
```

Setting this to `0` will cause all regenerated energy to be dissipated in the motor windings, preventing any regenerative current from reaching the bus up to the limit of the maximum configured current and system voltage. Setting it to `nan` (the default) disables the feature entirely.

This is most effective when used in conjunction with an acceleration limit.  The acceleration limit controls the rate at which braking torque is applied, and `max_regen_power_W` dissipates excess energy that makes it past the acceleration limit.

### Choosing a value

- If your supply cannot absorb any regenerative energy (e.g. a mains powered supply with no bus capacitance), set this to a small number like `10` or `0`.
- If your supply can absorb some current (e.g. a battery), set this to approximately `V_bus * I_charge_max`.  For example, a 24V battery that can accept 2A of charge current: `servo.max_regen_power_W 48`.
- If you are unsure, start with a value of `0` and increase it until you see fault 34 again, then back off by roughly 50%.

### Thermal considerations

The d-axis current injected by this feature dissipates power as heat in the motor windings.  At the maximum current (set by `servo.max_current_A`) with resistance R, the maximum sustained dissipation is `1.5 * I² * R`.  For a motor with R=0.05Ω and max current 40A, this is 120W.  Ensure the motor can tolerate the additional heating, particularly during sustained or repeated deceleration events.

## Lower the impedance of your input supply to regenerative power

By lowering the impedance of your input supply, you decrease the rate at which the voltage rises for a given amount of regenerative energy.  There are several approaches to this.

### Increase battery current rating

If you are using batteries that are capable of charging as your power supply, you can select batteries that have a higher charging current rating.

### Add bus capacitance

If you have a mains powered supply which is incapable of accepting regenerative energy, or it is not desirable to change the battery, you can add additional capacitance to the DC input bus.  There are several considerations when doing so:

- **Inrush current management**: Per [the electrical setup guide](../guides/electrical-setup.md#inrush-current-management), whatever inrush current management solution you are using must tolerate the additional capacitance.  If you are using a mjbots power_dist or mjpower-ss, the total system capacitance must be no more than 4000uF.  mains powered supplies may be able to handle much larger bus capacitances, although their reference documentation should be checked to validate that.  In general, the larger the capacitance the better for resolving over-voltage faults, presuming you stay within the limits of your inrush current solution.

- **Capacitor rating**: The selected capacitors should have a voltage rating sufficient for the maximum voltage the bus will expect with a design margin appropriate to your application.  Additionally, the ESR (equivalent series resistance), should be low enough to control the magnitude of the voltage rise.

### Switch to a battery

If you are using a mains powered supply, it may be possible to switch to a battery solution where the battery can be charged.  When doing so, it is important to ensure that inrush current is managed appropriately.

## Configuration changes

If the above solutions were unable to resolve the problem, or the system performance is still not at the desired level, there are a few other parameters which can help some, although not to the same degree.

### `servo.flux_brake_margin_voltage`

Flux braking works by monitoring a filtered version of the system voltage and dissipating more energy in the windings as this increases.  By increasing the range of voltages where this process occurs, the system will have more time to respond as the voltage rises.  The threshold points that are relevant are:

- `servo.max_voltage - servo.flux_brake_margin_voltage`: This voltage is the point where flux braking begins.
- `servo.max_voltage`: When the voltage reaches this point, the over-voltage fault will trigger.

You can increase `servo.flux_brake_margin_voltage` until the trigger point is maybe 1V above your nominal system voltage or fully charged voltage if on a battery.  You can also increase `servo.max_voltage` and `servo.flux_brake_margin_voltage` at the same time to give even more room.

### `servo.flux_brake_resistance_ohm`

This constant determines how much energy is dissipated in the windigs for a given amount of voltage rise.  Lower values are more aggressive and will dissipate more energy, but can be less stable.  Unless you have a good mechanism for verifying stability, it is not recommended to lower this more than a factor of 2x from the default.

### `servo.max_current_desired_rate`

This configuration value selects the maximum rate at which desired current can change.  By default, it is relatively slow at 10000A/s.  However, if you have raised it previously, lowering it back down can help reduce the rate at which regenerative power is increased.  If your application can tolerate it, lowering further will increase the effectiveness of flux braking.

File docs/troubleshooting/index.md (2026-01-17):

# Troubleshooting

Common issues and solutions for moteus controllers.

- [Calibration Issues](calibration.md) - Problems during motor calibration
- [No Motion](no-motion.md) - Motor not responding to commands
- [Limited Torque](limited-torque.md) - Motor not reaching expected torque
- [Gate Driver Faults](gate-driver-faults.md) - DRV8323 fault codes
- [Timeout Mode 11](timeout-mode-11.md) - Communication timeout errors
- [Overvoltage Fault 34](overvoltage-fault-34.md) - Regenerative braking issues

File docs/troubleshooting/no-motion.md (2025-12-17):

# Troubleshooting No Motion

You sent a command to moteus, or ran a script, but nothing moved.  This article will describe what steps you can take to diagnose and resolve the issue.

## Using tview

If you sent a `d pos` command from tview, there are a few possibilities.

**Invalid Syntax**: If the diagnostic channel responds with an OK, then this is not the problem.  If it responds otherwise, then the error message will give you a clue as to the problem.  The syntax for the `d pos` command can be found in the [diagnostic protocol reference manual]( http://localhost:8000/mjbots/moteus/protocol/diagnostic/#d-pos).

**Position Mode Fault**: If the diagnostic channel responded OK, then to identify the problem you must look at the current reported mode and fault status.  They will be present as the first two items in the `servo_stats` telemetry channel.  Common problems when first attempting control are:

 - "39 (outside bounds)": `servopos.position_min` and `servopos.position_max` are either not configured, or the motor starting position is outside the configured bounds.  Setting either to `nan` will disable it.
 - "33 (gate driver fault)": this indicates that the onboard MOSFET gate driver reported a fault.  To know which one, you will need to expand the `drv8323` telemetry channel.  The only "easy" problem to solve is `uvlo` which indicates that moteus attempted to draw more power than your supply could provide.
 - "43 (no position)": the most common reason for this fault is that the controller has not been calibrated yet.  See the [quick start section on calibration](../guides/calibration.md).

Once the cause of the fault has been identified, it can be cleared by sending:

`d stop`

Then the command in question can be attempted again.

## From a script or application

If you have a python script, C++ application, or other tool which is commanding moteus and it does not move, there are a few tools you can use.

**Request and display the mode and fault**: If your application does not already request and display the mode and fault it should do so.

**Log CAN-FD data**: If the application cannot be modified or it is difficult to do so, you can either (a) if it is using the python library use the `--can-debug OUT.LOG` command flag to save a record of all frames sent and received or (b) attach a second CAN-FD adapter to the bus and use it to log data.

Once you have data, it can be examined using `utils/decode_can_frame.py` to see what moteus is reporting.

Problems may be the same as from the "Using tview" section above.

Another common problem with applications using the register protocol (what the python and C++ library does), is watchdog timeouts.  For the register protocol, by default, moteus requires commands arrive at least every 100ms or it will enter mode 11, the timeout mode.  Once in this mode, a "stop" command must be sent to clear it.

The watchdog timer configuration is described in [the reference manual](../reference/configuration.md#servodefault_timeout_s).

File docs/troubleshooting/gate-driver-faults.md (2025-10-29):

# Troubleshooting Gate Driver Faults

Certain types of electrical problems in moteus can result in the onboard MOSFET gate drivers declaring an error condition.  When that happens, moteus will report fault 33.  This document describes how to troubleshoot the issue.

## Identifying the cause

To determine *which* fault the gate driver flagged, you need to look at the `drv8323` tree in tview or with `python -m moteus.moteus_tool -t 1 --read drv8323`.  Each fault has a different boolean value associated with it, and multiple can be flagged at the same time.  From a diagnostic perspective though, they boil down into two categories:

## Recoverable faults

The only fault type that, if repeatable, is easily recoverable is the `uvlo=true` fault.  This means that the gate driver identified the input supply voltage dropped below the minimum operation threshold.  It happens when moteus attempts to draw more power than the supply or battery can provide.  Depending upon the cause, there are several potential resolutions:

**moteus needs to output more torque/power**: If the fault triggered but moteus was not yet applying sufficient torque for your application, then you must change your supply to be able to provide more power.  If the supply is a current limited lab supply, you could increase the current limit.  If it is a fixed current wall supply, you could switch to one with a higher power output.  If it is a battery, you could switch to one with a higher peak current rating.  It is also possible to occur due to poor supply wiring, i.e. if the resistance of the supply power cables is too high.

**moteus should not attempt to draw that much power**: If moteus was attempting to apply more torque or power than is desirable, there are two limits which can be adjusted.

1. `servo.max_current_A` - This will determine the maximum phase current moteus can output and will correspond to the maximum amount of torque it can output.  This does not directly correlate with supply power, as the supply power required also scales linearly with the motor velocity.  However, it is good to ensure this is not set larger than it needs to be.
2. `servo.max_power_W` - This will determine the maximum amount of power moteus can output to the motor, and thus roughly the amount of supply power it can consume.  If using a power supply with known voltage and current capability, you can set this to be some fraction of that power to leave sufficient margin.

## Unrecoverable faults

Most non-uvlo faults the gate driver reports indicate that the controller has suffered electrical damage.  Most of the reasons are laid out in the electrical section of the user guide:

- [Using moteus: Electrical](../guides/electrical-setup.md)

i.e. poor wire construction can result in micro-arcing which further causes large voltage transients either at the supply terminals, or the motor phase terminals.  Lack of inrush current management also results in large voltage transients at the supply terminals.  Poor strain relief of XT30 connectors, once again, can cause micro-arcing and large voltage transients.

In these cases, it may be possible to recover the controller by replacing components, but doing so requires moderate to advanced SMT rework capabilities that are beyond most users.  Usually the appropriate action is to identify which of the electrical installation guidelines were not adhered to, address them, then replace the controller with a new one.

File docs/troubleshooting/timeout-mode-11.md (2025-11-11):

# moteus reports mode 11 - Timeout

After performing some initial validation using tview, maybe you port your motion profile to a python or C++ application to get ready for a deployment.  However, often users at this point will start seeing moteus enter mode 11, the timeout mode, after which it stops accepting commands and acts to damp motion.  This guide tells you why that happens and how to fix it.

## Rationale

moteus implements a "watchdog timer" for commands that arrive over CAN-FD.  Once any command is received, the next one must be received within a certain time period.  If it doesn't, then moteus will enter the timeout mode.

There are a few reasons for this feature:

1. **Safety**: In an actual deployment, moteus could have been commanded to make a large or fast movement indefinitely.  If your application crashes, or the computer hosting it is powered down, you probably don't want moteus continuing.
2. **Convenience**: When testing an application, if you exit the application you typically want moteus to stop doing whatever it was doing as well.

Once in the timeout mode, moteus will only leave it upon receiving a stop command.  This prevents moteus from resuming unexpectedly.

When using diagnostic mode commands like when typing into the diagnostic channel console in tview, moteus defaults to an infinite watchdog duration for the sake of convenience.  This is why the problem most often appears after switching to a script.  Both the python and C++ library default to using the more efficient register mode commands.

## Fixes

If you get the timeout here are ways to resolve it:

### Disable or extend the timeout duration

The length of time moteus waits is configurable at:

```
servo.default_timeout_s
```

[(listed here in the reference)](../reference/configuration.md#servodefault_timeout_s)

To disable it, use `nan`, otherwise specify a floating point number of seconds.

### Structure your application to send commands at a regular interval

To maintain the benefits of the watchdog, your application needs to continually send commands to moteus.  That means even when the application is waiting, it still needs to be sending commands.  Fortunately, for many moteus commands, if the target velocity was 0, you can keep sending the same command over and over again.

=== "Python"

    ```python
    # Don't do this:
    #  await asyncio.sleep(5)

    # Instead, do this:
    start = time.time()
    while time.time() - start < 5:
      await c.set_position(velocity=0.0, query=True)
      await asyncio.sleep(0.02)
    ```

=== "C++"

    ```cpp
    // Don't do this.
    //  ::usleep(1000000);

    // Instead, do this:
    #include <chrono>

    double get_time() {
      using namespace std::chrono;
      return duration<double>(system_clock::now().time_since_epoch()).count();
    }

    int main() {
      // setup ...

      const auto start = get_time();
      while (get_time() - start < 5) {
        mjbots::moteus::PositionMode::Command cmd;
        cmd.velocity = 0.0;
        cmd.position = NaN;
        c.SetPosition(cmd);

        ::usleep(10000);
      }

      return 0;
    }
    ```

### A combination of the above two

It may be that even after restructuring your application to send commands more regularly, it makes sense to increase, but not disable the default watchdog timeout.

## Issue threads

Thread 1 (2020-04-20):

hi. can you upload the step files ?

rippschemitkraut, 2020-04-20:
hi. can you upload the step files ?
thx.

jpieper, 2020-04-20:
Thanks for you interest!  At the moment, the CAD files that are currently uploaded (F360 exports from an indeterminate point in the past), is all you're going to get.

jpieper, 2020-04-21:
I suppose if there is some specific model you'd like in STEP format, let me know and your email address, and I can export it for you from Fusion.

jpieper, 2020-04-28:
Closing this after no feedback for a week.

rippschemitkraut, 2020-04-29:
hi, didnt see this email. my email is shellbomber@gmail.com -   thx anyway

Am Di., 28. Apr. 2020 um 19:01 Uhr schrieb jpieper <notifications@github.com
>:

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

Closed 2020-04-28.

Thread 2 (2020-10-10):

FAILED: Build did NOT complete successfully

rituraj-01, 2020-10-10:
We have bought the moteus r4.3 developer kit. Following the video and github tutorial, I'm getting the compilation error.
I'm following [](https://github.com/mjbots/moteus/blob/master/docs/getting_started.md),
`On running this tools/bazel test -c opt --cpu=stm32g4 //:target`, it compiles with some downloading errors, but I fixed them by manually downloading the files.
but on running `tools/bazel test --cpu=k8 //:host`, I'm I'm getting the following error

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

[Error-1.txt](https://github.com/mjbots/moteus/files/5359153/Error-1.txt)

`sacgc@sacgc-VirtualBox:~/Documents/moteus$ tools/bazel test --cpu=k8 //:host
INFO: Analyzed 3 targets (0 packages loaded, 0 targets configured).
INFO: Found 3 test targets...
ERROR: /home/sacgc/Documents/moteus/moteus/tool/BUILD:38:11: C++ compilation of rule '//moteus/tool:moteus_tool_lib' failed (Killed): clang-clang failed: error executing command external/com_github_mjbots_rules_mbed/tools/cc_toolchain/wrapper/clang-clang -MD -MF bazel-out/k8-opt/bin/moteus/tool/_objs/moteus_tool_lib/moteus_tool.d ... (remaining 79 argument(s) skipped)

Use --sandbox_debug to see verbose messages from the sandbox clang-clang failed: error executing command external/com_github_mjbots_rules_mbed/tools/cc_toolchain/wrapper/clang-clang -MD -MF bazel-out/k8-opt/bin/moteus/tool/_objs/moteus_tool_lib/moteus_tool.d ... (remaining 79 argument(s) skipped)

Use --sandbox_debug to see verbose messages from the sandbox
INFO: Elapsed time: 114.111s, Critical Path: 62.59s
INFO: 17 processes: 17 linux-sandbox.
FAILED: Build did NOT complete successfully
//moteus:dummy_host_test                                              NO STATUS
//moteus:test                                                         NO STATUS
//moteus/tool:test                                              FAILED TO BUILD

FAILED: Build did NOT complete successfully
`

I'm running ubuntu 18.04 on Virtual Machine.
Please help

jpieper, 2020-10-10:
It says `(Killed)` which makes me think maybe you ran out of memory or disk space.  Can you run `dmesg` and see if the kernel reported an out of memory error?

rituraj-01, 2020-10-10:
Yes it is showing out of the memory. do you have some suggestions for configuration on Virtual Machine. I have given it 2GB of RAM access.

jpieper, 2020-10-10:
I don't know exactly how much is necessary.  I would expect you should have at least 4G.

jpieper, 2020-10-10:
Were you able to get it working?

rituraj-01, 2020-10-10:
There was one more problem occurred, related to some package. If I fail to solve it, I'll need this thread.

rituraj-01, 2020-10-11:
Whie Running the `./bazel-out/k8-opt/bin/moteus/tool/tview --devices=1` command. I'm getting error
```
Falling back to PySide1
Gtk-Message: 10:25:41.876: Failed to load module "canberra-gtk-module"
Traceback (most recent call last):
  File "/home/sacgc/Documents/moteus/./bazel-out/k8-opt/bin/moteus/tool/tview.runfiles/com_github_mjbots_moteus/moteus/tool/tview.py", line 1154, in _handle_user_input
    device_nums = [self.devices[0].number]
IndexError: list index out of range
```

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

rituraj-01, 2020-10-11:
I solved the module problem (Gtk-Message: 10:25:41.876: Failed to load module "canberra-gtk-module") by installing following modules:
`sudo apt install libcanberra-gtk-module libcanberra-gtk3-module`

but it still shows:
`Falling back to PySide1`
and doesn't loads the GUI.

jpieper, 2020-10-11:
My guess is that you're having problems passing through USB to your VirtualBox.  Can you verify that `/dev/ttyACM0` is present there?

Also, I can help you faster/in-real-time if you're willing to join discord: https://discord.gg/W4hUpBb  The #moteus channel is a fine place to ask questions.

rituraj-01, 2020-10-11:
Thank you @jpieper I used a different virtual machine and it worked.

Closed 2020-10-11.

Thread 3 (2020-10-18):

Schematics are empty

PapyP, 2020-10-18:
Hello,

What software do you use to make the schematics ? I tried to open them with Altium Designer and Kicad. In kicad I have an error and in altium I have empty sheets.

Thanks

jpieper, 2020-10-18:
Eagle

PapyP, 2020-10-28:
Thank you !

Closed 2020-10-28.

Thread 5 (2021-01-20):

moteus_tool cannot complete many tasks if telemetry channels are enabled

jpieper, 2021-01-20:
Repro:

1. Start tview
2. Expand something to get data
3. Exit tview
4. Try to calibrate the servo using moteus_tool

That, and many other operations will fail because moteus_tool doesn't expect the servo to be spewing.

Closed 2021-03-09.

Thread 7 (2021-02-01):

Windows 10, tview console err unknown name.. Ubuntu "No such device"

ragemaster, 2021-02-01:
under Windows 10, tview console err unknown name.. and no telemetry data however in the console is shows readings from the device.. nothing else happens as demonstrating in your getting started video..
Tried to get it to work in Ubuntu 20.04 and the terminal output says this:
File "/home/terrence/.local/lib/python3.8/site-packages/moteus_gui/tview.py", line 856, in _make_transport
    return moteus.get_singleton_transport(self.options)
  File "/home/terrence/.local/lib/python3.8/site-packages/moteus/moteus.py", line 120, in get_singleton_transport
    raise RuntimeError("Unable to find a default transport, tried: {}".format(
RuntimeError: Unable to find a default transport, tried: (<moteus.moteus.FdcanusbFactory object at 0x7fd01ef87a90>, "[Errno 13] could not open port /dev/serial/by-id/usb-mjbots_fdcanusb_299C5406-if00: [Errno 13] Permission denied: '/dev/serial/by-id/usb-mjbots_fdcanusb_299C5406-if00'"),(<moteus.moteus.PythonCanFactory object at 0x7fd01ef87ac0>, '[Errno 19] No such device')

jpieper, 2021-02-01:
1) For Ubuntu, that error message indicates that you do not have permission to read the USB serial device.  You could try installing the `70-fdcanusb.rules` following the instructions at the top of the file: https://github.com/mjbots/fdcanusb/blob/master/70-fdcanusb.rules

2) For Windows, It is unclear exactly what error message you got.  Did you install `moteus-gui`, then were unable to type `tview` at a command prompt because it said no such command or file name?  You may have to run the program as `python3 -m moteus_gui.tview` if you didn't configure python to put user scripts in your system path.

ragemaster, 2021-02-02:
still cant get windows 10 running however the for linux udev rules works! now my wheels can spin, Thanks

jpieper, 2021-02-02:
Great!  If you want to get Windows working, come over to the discord where we can help you interactively: https://discord.gg/W4hUpBb

Closed 2021-02-02.

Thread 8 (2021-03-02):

fdcanusb auto-detection does not work on Macs

jpieper, 2021-03-02:
If you try to run tview with no arguments, or use the python-library's auto-detection capabilities on a Mac, it will pick a `/dev/cu.usbmodem` device, which is not suitable to use.

I need to have a volunteer who can write python and has a Mac to fix this.

jpieper, 2021-03-09:
One person did test this, and found that it picked a serial port, but picked one that started with `cu` instead of `tty`.  So now I need a Mac volunteer who can write python to help fix this.

jpieper, 2022-05-29:
I have had reports of this working correctly on Macs now.

Closed 2022-05-29.

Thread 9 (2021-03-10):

tview fails to start on a MPC2517/8 board from the raspberry pi

jpieper, 2021-03-10:
The initial `conf enumerate` catches a stale `OK` from the `tel stop` and then doesn't see the actual result.

Observed in moteus-gui 0.3.15 on a rpi.

jpieper, 2021-03-12:
Well, I've set up an rpi3 with the mpc2518 based Seeed board and in a dozen restarts of tview can't get it to reproduce.  Guess I'll try making a version with some more logging and see if the OP can run with that to better understand what is happening.

jpieper, 2021-06-16:
Closing this because we either got it working, or it was overtaken by events.

Closed 2021-06-16.

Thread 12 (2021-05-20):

tview scaling issue after removing plot

xninop, 2021-05-20:
Using a moteus developer's kit, in tview, I am seeing some weird behaviour that I have been able to recreate. If you choose to plot, let's say, unwrapped_position from servo_stats, and send it to plot left, then send filt_fet_temp_C, for example, to plot right, wait a bit then "remove" the first stat from the display area, the visible window of the remaining plot gets smaller and smaller and the x-axis coordinates sometimes even jump around, I've seen, becoming negative, if you wait long enough. The "old" plotted values start getting erased from the left when the plot reaches about 1/4 of the grid from the left until the remaining visible plot is bunched up at the right of the display area.

jpieper, 2021-05-21:
Note, you can work around this by adding any plot to the left axis again.  i.e. once you've used an axis, always use the axis.  This is a bug in matplotlib, I'll look to see if there is some way to work around it.  removing things is only kinda supported there already.

Closed 2021-05-21.

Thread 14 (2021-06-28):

Getting started does not explain how to calibrate the controller

Nate711, 2021-06-28:
Am I missing something or does the getting started guide not explain how to calibrate the controller? Thanks. https://github.com/mjbots/moteus/blob/main/docs/getting_started.md

jpieper, 2021-06-28:
The getting started guide is aimed at the devkit, which comes calibrated from the factory.

jpieper, 2021-07-12:
I did add a reference in ef86e2a506ff27af017b6f994941b36b6b1abafe

Closed 2021-07-12.

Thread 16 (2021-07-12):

tview on a pi3hat with multiple servos does not work reliably

jpieper, 2021-07-12:
Running tview on a pi3hat with multiple servos often results in desynchronization of the command stream.  Power cycling sometimes resolves it, and sometimes doesn't.

jpieper, 2021-07-12:
A reported recipe is to put 2 servos on bus 3, then start tview with `sudo tview --pi3hat-cfg '3=3,4' -t3-4`

jpieper, 2021-07-15:
I've now tested locally with two servos, id 3 and 4, on bus 3 of a pi3hat and was unable to make it fail.  This was with a pi3hat r4.4b, and packages:

```
moteus 0.3.25
moteus-gui 0.3.25
moteus-pi3hat 0.3.12
```

I started up tview, it enumerated everything fine.  Then I expanded multiple channels on each servo, plotting some random values, and everything kept working.  I did this 6 or 7 times with no issues, across 3 power cycles.

To make progress here, I'll probably need to provide the reporter with instrumented packages that collect debugging information.

jpieper, 2021-12-17:
Haven't had any more reports of this, so calling it not a problem for now.

Closed 2021-12-17.

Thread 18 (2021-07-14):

add description of derate_current_A to reference.md

Fellfalla, 2021-07-14:
Currently, reference.md is missing out the description of the `derate_current_A` parameter.

jpieper, 2021-07-14:
Thanks for the report!  That value, while configurable, isn't something that you should be modifying unless you are comfortable reading the source to figure out what it does.  Thus, its undocumented nature.

Closed 2021-07-14.

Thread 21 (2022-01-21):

When I send a cmd to mjbots via fdcan, mjbots only responds the first cmd and no message reply.

Mu-feng, 2022-01-21:
When I use FDCAN command to control the motor, it only responds to the first command and does not reply.Then if I send a command again and again, it has a very small accumulation of responses, with no reply.
I observered the fdcan-cmd that i have sent, and found it is corrected.
So, I am very conffused about this scene.
Do you have any solution for this?

jpieper, 2022-01-21:
We can help you debug, although it may take a few back and forths.  Are you able to join the mjbots Discord at: https://discord.gg/W4hUpBb  as real-time back and forth will be faster.

If not, the first question is:

First, what CAN transceiver are you using and what software are you using send and receive CAN commands?

Mu-feng, 2022-01-21:
What I used is BUSMASTE USB-CAN and its software is BUSMASTE.
I send this two cmd for different torque, one of  is "01 00 09 06 1C 01 00 00 00 14 04 00", and another is "01 00 08 06 1C 20 00 00 00 14 04 00".
Final, thanks for your help and I have registered Mjbots Discord as you said.

jpieper, 2022-01-21:
Great, can you post a message in the #moteus channel and we can start debugging?

Mu-feng, 2022-01-21:
Ok, thank you.
I will post it later.

jpieper, 2022-02-16:
Closing this as I believe it was resolved out of band.

Closed 2022-02-16.

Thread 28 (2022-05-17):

how can use

ou1443989517, 2022-05-17:
I want to directly call the code based on moteus to control and query the information of the motor, how can I do it？

jpieper, 2022-05-17:
Are you asking how to use the python bindings?  Have you seen the example in: https://github.com/mjbots/moteus/blob/main/lib/python/examples/simple.py

ou1443989517, 2022-05-17:
> 您是在问如何使用 python 绑定？您是否看过以下示例：[https ://github.com/mjbots/moteus/blob/main/lib/python/examples/simple.py](https://github.com/mjbots/moteus/blob/main/lib/python/examples/simple.py)

Thank you for your reply, yes I have seen it, but the code inside simple will stop the running motor, I also used the method inside https://pypi.org/project/moteus/ like pr. position = moteus.INT16
c = moteus.Controller(position_resolution=pr) This seems to be an address printed out using print, not the desired value

ou1443989517, 2022-05-17:
> 您是在问如何使用 python 绑定？您是否看过以下示例：[https ://github.com/mjbots/moteus/blob/main/lib/python/examples/simple.py](https://github.com/mjbots/moteus/blob/main/lib/python/examples/simple.py)
e.g:<memory at 0x7ff7dd09dac0>

jpieper, 2022-05-17:
I'm sorry, but am unable to understand the problem you have.  Could you please share a full script, and exactly what you expect it to do or print out?

Are you saying if you run `simple.py` it prints out addresses?  Local testing does not do that.

ou1443989517, 2022-05-18:
Sorry, there is something wrong with my expression, here is my code
`parser_test= argparse.ArgumentParser()
max_receive_bytes=48,
args = argparse.Namespace(target=[], can_prefix=0, verbose=False,
                          tel_stop=False, no_tel_stop=False, fdcanusb=None,
                          fdcanusb_debug=None, can_iface=None, can_chan=None,
                          force_transport=None, stop=False, info=False,
                          console=False, dump_config=False, write_config=None,
                          flash=None, no_restore_config=False,
                          bootloader_active=False, calibrate=True, cal_invert=False,
                          cal_bw_hz=100.0, encoder_bw_hz=None, cal_no_update=False,
                          cal_ll_encoder_voltage=None, cal_ll_encoder_speed=1.0,
                          cal_ll_resistance_voltage=None, cal_ll_kv_voltage=None,
                          cal_power=None, cal_speed=None, cal_voltage=None,
                          cal_kv_voltage=None, cal_motor_power=5.0,
                          cal_motor_speed=6.0, cal_max_remainder=0.1,
                          cal_raw=None, restore_cal=None, zero_offset=False)
args.devices=['1']
async def main():
    transport = moteus.Fdcanusb()
    pr=moteus.PositionResolution()
    pr.velocity=moteus.INT16
    c=moteus.Controller(position_resolution=pr)
    print(c)`
My purpose is to get the speed and torque value of the motor output like the Tview.py you wrote. I want to do something with these values

jpieper, 2022-05-18:
You need to call methods on the `Controller` instance to either send commands or make queries.

For instance:

```
async def main():
  # stuff
  c = moteus.Controller()
  result = await c.query()
  print(result)
  result = await c.set_position(position=1.0, query=True)
  print(result)
```

ou1443989517, 2022-05-18:
Cool, I will try out the code.
Well, my question is how can I use python binding to query detailed stats of the motor just like those inside the 'servo_stats' in the telemetry widget in tview?

jpieper, 2022-05-18:
The information in tview is queried using the "diagnostic" interface, which is distinct from the "register" interface.  It is not recommended for real-time use.  You can use it from python though, like so:

```
async def main():
  # stuff
  c = moteus.Controller()
  s = moteus.Stream(c)
  result = s.read_data("servo_stats")
  print(result)
```

ou1443989517, 2022-05-18:
servo: <coroutine object Stream.read_data at 0x7f7c2002e340>,This is the value I print out, which seems to be an address

jpieper, 2022-05-18:
I edited it shortly after posting to include an `await`

If you do not await an asynchronous function, it is not actually called.

```
  result = await s.read_data("servo_stats")
```

ou1443989517, 2022-05-18:
I got it! thanks
I got a few questions.
For real time use with python will dumping info like this in a loop take up too much bandwidth when I connect more motors using fdcan?
Also, is it possible to query only certain keys of the servo_stats?

ou1443989517, 2022-05-18:
good！I can

jpieper, 2022-05-18:
As mentioned, the diagnostic interface is not intended for real time use. It both requires lots of bandwidth, and can potentially become inconsistent.  It is also undocumented, and not guaranteed to be stable across firmware versions.  It is not possible to query only individual keys.

The register interface is intended for real time use.

https://github.com/mjbots/moteus/blob/main/docs/reference.md#a2b-registers

What data do you want that you are not able to get from it?

ou1443989517, 2022-05-19:
Thanks, I have no more questions. Thank you for the reply.

Closed 2022-05-19.

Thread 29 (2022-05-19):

Direct torque control with python

iseeag, 2022-05-19:
Been experimenting using python lately. I wonder the best way to torque control the motor, so by looking at the reference, if I want to set torque to 0.8, I should do this:
```
...
    state = await c.set_position(feedforward_torque=0.8,
                                 kp_scale=0,
                                 kd_scale=0,
                                 query=True)
...
```
Is this even correct?  Thanks!

jpieper, 2022-05-19:
Yes, that command a torque of 0.8Nm.  Do note that with the register protocol, there is by default a watchdog timeout that requires you send that command repeatedly at least every 100ms or the controller will enter a fault state: https://github.com/mjbots/moteus/blob/main/docs/reference.md#servodefault_timeout_s

jpieper, 2022-05-29:
I'll consider this resolved.

iseeag, 2022-05-30:
Thanks heaps!

Closed 2022-05-29.

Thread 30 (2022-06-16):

specs in README ?

nathmo, 2022-06-16:
hey would you think it would be okay to add a section like that in the README with the price and other important specs ?
thanks a lot

## Key specs
| Specification              | Rating          |
| ---------------------------|:---------------:|
| Dimensions                 | 46 x 53 mm      |
| Mass                       | X g             |
| Power source voltage       | X-Y V           |
| Peak current               | XA continuous, Y 2 sec   |
| Magnetic sensor resolution | 14 bits, AS5147 |
| Price Avg                  | XX $            |
| number of brushless output | 1               |
| MCU                        | STM32           |
| communication              | CAN             |

jpieper, 2022-06-17:
Great idea, thanks!  https://github.com/mjbots/moteus/commit/dee768c28d6d7b4be83436cca813897c4a9b573f

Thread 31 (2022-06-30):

Sending a "stop" immediately after a control command can cause an assertion

jpieper, 2022-06-30:
If the following sequence of CAN commands is sent at the line rate with no delay:

* stop
* position
* stop

Then the controller can get confused while trying to calibrate the drv83x3 current sense amplifiers and assert.

jpieper, 2023-08-22:
Fixed in b7f3908b08595a92edd6824a0f2cf74bc8f6cd73

Closed 2023-08-22.

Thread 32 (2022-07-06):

Tview: unexpected keyword argument

Fergus-MW, 2022-07-06:
Freshly installed tview using pip, getting this error everytime and can't interact with motor controller.
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

jpieper, 2022-07-06:
You need to upgrade your `moteus` library, it seems the pip version requirements aren't completely correct.

If you installed them in your user account, it would be `pip3 install --upgrade moteus`  if as root it would be `sudo pip3 install --upgrade moteus`

Fergus-MW, 2022-07-06:
Updated moteus from 0.3.16 to 0.3.42 and that fixed it. Thanks for the fast reply!

jpieper, 2022-07-06:
No problem!

jpieper, 2022-07-06:
For good measure: https://github.com/mjbots/moteus/commit/9e0758333c190a2a73538bcc91ca479d91e8da34

Closed 2022-07-06.

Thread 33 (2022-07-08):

motor_position.output.sign doesn't work

jpieper, 2022-07-08:
It is supposed to change the sign of the output (and of the control).  As of 2022-07-08, it only affects a few initialization scenarios.

Closed 2022-07-11.

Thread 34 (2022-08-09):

TypeError: make_rezero() got an unexpected keyword argument 'cmd'

killianstorm, 2022-08-09:
Hi,

- System: Raspberry Pi Model 4 B
- Moteus version: 0.3.43
- Type of error: TypeError

Calling the function `set_rezero` in `moteus.py` raises a `TypeError` for version `0.3.43`.

I get the following output:
`File "/home/pi/w3_arm_research/actuator/src/controller/venv/lib/python3.9/site-packages/moteus/moteus.py", line 723, in set_rezero
    [self.make_rezero(**kwargs, cmd=cmd)]))
TypeError: make_rezero() got an unexpected keyword argument 'cmd'`

At a quick glance it seems that the passed argument `cmd=cmd` is wrongly passed. Removing it makes the function callable again.

Do I have a version mismatch or is this argument indeed wrongly passed?

Thanks!

jpieper, 2022-08-09:
Yep, that's a bug.  Should be fixed here 150d68fe953a1d8656bfe8e056e61ce87cc74575  and in version 0.3.44 on pypi

Can you confirm?

killianstorm, 2022-08-10:
All good, thanks for the quick response!

Closed 2022-08-10.

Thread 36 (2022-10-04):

Digital out not working on 4.11

radu-vdt, 2022-10-04:
Cannot figure out how to change digital outs through the tview interface.

Setting `aux[12] out 15` sets aux[12]/pins[12] to True when they are set to mode.digital_out,  but the voltmeter always reads 3.3V on the Aux2 outputs and ~0.3V on the Aux1 outputs.

radu-vdt, 2022-10-04:
Traced to aux1.spi mode resetting to `builtin` even when configured as disabled - closing

Closed 2022-10-04.

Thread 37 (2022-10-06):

Motor position going out of range even if motor is held in place

kibidev, 2022-10-06:
Holding a motor in place (at e.g. position ~0) will still stop as at position servopos.position_min/max after a while when a velocity is set.
This is tested in velocity mode (setting kp=0, ki=0).

Running attached code with motor unobstructed will case position limit to be reached after ~10 seconds, and motor will stop (expected behavior).
When obstructing the motor and running the code, the motor will still stop after ~10s, reported position will stay at ~0 the entire time.

There seems to be some sort of internal state/calculated position that triggers position limits as well.
Is this intentional?
Can it be disabled somehow?

```
import moteus
import asyncio
import math

async def run():
    controller = moteus.Controller()
    stream = moteus.Stream(controller)
    await controller.set_stop()
    await controller.set_rezero()
    await stream.command(b'conf set servopos.position_min -10.0')
    await stream.command(b'conf set servopos.position_max 10.0')

    await stream.command(b'conf set servo.default_accel_limit 5.0')

    await stream.command(b'conf set servo.max_velocity 7.0')
    await stream.command(b'conf set servo.default_velocity_limit 5.0f')

    # Velocity control
    await stream.command(b'conf set servo.pid_position.kd 0.2')

    # Deactivate position controller
    await stream.command(b'conf set servo.pid_position.kp 0.0')
    await stream.command(b'conf set servo.pid_position.ki 0.0')
    await stream.command(b'conf set servo.pid_position.ilimit 0.0')
    await stream.command(b'conf set servo.pid_position.iratelimit 0.0')

    while True:
        telemetry = await controller.set_position(position=math.nan,
                                            stop_position=math.nan,
                                            velocity=1.0,
                                            maximum_torque=0.2,
                                            query=True)
        print(telemetry)

asyncio.run(run())
```

kibidev, 2022-10-06:
Tested with FW versions:
20220501-moteus-0965b28edd417f4e935f87d1ad40a607093d816f.elf
20220730-moteus-75df0139aaf6e76f207dffae17b81b39f3d5d5ce.elf
20220803-moteus-26e636ddb36b702a361291b0ab842acd881f281b.elf

Tested on HW model 800 and 700.

jpieper, 2022-10-06:
If you have the `kp` term set to 0, then setting `servo.max_position_slip` to 0 will have no other effect.  However, the combination of those two means that the velocity control has no effective integrative term, and in steady state the velocity will never match the control velocity in the presence of an external torque.  If you need the velocity to track accurately, you should use non-zero values for both.  The `kp` will control the "velocity integrative term", and the `max_position_slip` will control the integrator windup limit.

kibidev, 2022-10-06:
Great, thanks again.
Accurate velocity is not important in our application, so it should be good like this.

jpieper, 2022-10-06:
Great, I'll close this out then.  Come back if you have more questions, or join the mjbots discord!  https://discord.gg/W4hUpBb

Closed 2022-10-06.

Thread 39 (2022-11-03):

Suggestion - Enable Discussions / Query over EtherCat

grbd, 2022-11-03:
Hi,
I was wondering if it might be an idea to enable discussions in the github settings for the repo?

Also I was wondering if there had been any thoughts on the use of EtherCat?
There's the Trinamic TMC8462A-BA which is a BGA part
It seems to be around only £20 or so it would be interesting if this could be integrated into the Moteus
(especially now that ODrive has gone closed source)
maybe as an addon board.

  * https://www.farnell.com/datasheets/3119187.pdf
  * https://www.farnell.com/datasheets/3119187.pdfhttps://www.trinamic.com/fileadmin/assets/Products/Eval_Documents/TMC8462-EVAL_user_manual_rev1.00.pdf

jpieper, 2022-11-03:
Hi and thanks for your interest!

At the moment, despite it not being ideal for all types of interaction, I'm trying to keep design discussions and such in the mjbots Discord: https://discord.gg/W4hUpBb

And no, there are no plans within mjbots to support EtherCat.  As you noted, the design is open source, so you are free to modify it to add support yourself!

grbd, 2022-11-03:
Ok

Closed 2022-11-03.

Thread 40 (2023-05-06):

MAX15062AATA+T in the n1 circuit should rather be MAX15062BATA+T

Fellfalla, 2023-05-06:
The label of the 5V voltage supply in the n1 .sch seems to be erroneously still the converter of the r4.11 version.

Change MAX15062AATA+T -> MAX15062BATA+T

jpieper, 2023-05-06:
Thanks!  I'll get this or something similar merged.  FYI, the eagle `MPN` attribute is the source of truth for part selection.  Everything else has risks of being lies.

jpieper, 2023-07-23:
Fixed in: dc715007c683322852fb92333ad146a01155c14e

Closed 2023-07-23.

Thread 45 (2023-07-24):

Feature request: Jerk limiting

saosebastiao, 2023-07-24:
Hi, thanks for the project. I recently bought the dev kit and I’m exploring the code base. One of the things that can be incredibly useful on servo motors is limiting jerk (first derivative of acceleration). On CNC machines, jerk limitation helps remove potential sources of hardware failure, miscalibration, drift, and overshoot. I’d imagine it is also quite helpful with robotics, as those are shared concerns.

There are quite a few CNC controllers which implement jerk limiting, one excellent example being [g2core](https://github.com/synthetos/g2). While useful at the CNC controller level, I think it actually a much better fit when limited at the motor controller level, as it has access to data on current, torque, backemf, and temperature, which could potentially enable more sophisticated control regimes than PID control, such as Model Predictive Control.

I’m still familiarizing myself with the codebase, but would you be willing to accept outside code contributions? I wouldn’t mind giving it a try myself, along with a few other features that I think would be great and potentially worthwhile to other users (for example, integration with OpenCyphal).

jpieper, 2023-07-24:
I agree jerk limited trajectories can be valuable!

Well, moteus is open source so even if it isn't accepted upstream and you implement it, you can use it!

Jerk limiting of the trajectory is nominally separate from other more advanced control like MPC, but if you're patient and willing to fit things within the timing constraints and architecture, feature contributions of any sort are certainly welcome!

thestumbler, 2023-07-24:
I did a constant jerk in my application. I can see the benefits of having that in the controller, but not sure big of a headache that would be. Interesting, the comment that limiting jerk limit will reduce wear and tear on mechanical parts.

saosebastiao, 2023-07-25:
Yeah, Jerk limited trajectories are a different concern than MPC, I guess I'm thinking a few steps ahead. My thought process was if we have jerk limited trajectories, then it would also be useful to add feed-forward control to PID, but it might be better implemented as MPC. Either way, that's just my brain running amok.

Could you elaborate on the timing constraints? Are you talking about meeting the specified control rate?

Also, could you enable the Discussions feature on the repo? I have a few things I'd like to discuss with you or the community, but they're not really a great fit for issues, and I don't want to be a nuisance.

jpieper, 2023-07-25:
There are a fixed number of execution cycles available within the control loop.  You probably add around 50-100 ARM cycles to the base cycle count without finding ways to speed up other parts.  There is a HIL test fixture which verifies that this holds across all the features tested using the following script: https://github.com/mjbots/moteus/blob/main/utils/firmware_validate.py

I'm not going to enable Discussions for now, but there is a Discord which is intended to serve a similarish purpose: https://discord.gg/W4hUpBb

jpieper, 2024-08-01:
Given that it has been about a year with no updates, I'm going to close this out for now.

Closed 2024-08-01.

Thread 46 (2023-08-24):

Just reading data from controller

Andreasgdp, 2023-08-24:
When using either cpp og python library, I can't seem to figure out how to just read the data from the controller.

# Use case
When developing a control system it is required to be able to know the states of the system at all times, i.e. also before any movement action has taken place.

# Current examples
In the examples given, the data is gotten after requesting a movement like:

```Python
state = await c.set_position(position=math.nan, query=True)

        # Print out everything.
        print(state)

        # Print out just the position register.
        print("Position:", state.values[moteus.Register.POSITION])
```

or

```cpp
    cmd.position = std::numeric_limits<double>::quiet_NaN();
    cmd.velocity = 0.0;

    const auto maybe_result = controller.SetPosition(cmd);
    if (maybe_result) {
      const auto r = maybe_result->values;
      ::printf("%3d p/v/t=(%7.3f,%7.3f,%7.3f)  v/t/f=(%5.1f,%5.1f,%3d)   \r",
             static_cast<int>(r.mode),
             r.position,
             r.velocity,
             r.torque,
             r.voltage,
             r.temperature,
             r.fault);
      ::fflush(stdout);
    }
```

# Current alternative being used
I am primarily using CPP and have been using @sinaaghil's wrapper for the moteus driver, since he has implemented a way to read state, and not first request a position change.
Example:
https://github.com/sinaaghli/moteusapi/blob/main/example_internal/main_readstate.cpp

# If already possible
If it is already possible to just read the state using the libraries, it would be appreciated if an example of how this is done, was added to the libraries for ease of use and understanding.

jpieper, 2023-08-24:
In python do:

```
result = await c.query()
```

And in c++, do:

```
auto maybe_values = c.SetQuery();
```

Is that what you are looking for?

jpieper, 2023-08-24:
While there is not standalone documentation, the main python file and the main C++ header file are designed to be easy to read in order to discover all the available APIs:

https://github.com/mjbots/moteus/blob/035fe7915c2f9ddf4a25b15b0bc5fddc7e77f4a1/lib/python/moteus/moteus.py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
https://github.com/mjbots/moteus/blob/035fe7915c2f9ddf4a25b15b0bc5fddc7e77f4a1/lib/cpp/mjbots/moteus/moteus.h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

jpieper, 2023-08-24:
And finally, there are examples of using both APIs in the existing examples:

https://github.com/mjbots/moteus/blob/035fe7915c2f9ddf4a25b15b0bc5fddc7e77f4a1/lib/python/examples/gpio.py#L57
https://github.com/mjbots/moteus/blob/035fe7915c2f9ddf4a25b15b0bc5fddc7e77f4a1/lib/cpp/examples/nlateral_teleop.cc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

Andreasgdp, 2023-08-24:
Yes perfect `auto maybe_values = c.SetQuery();` is working flawlessly. For me it just wasn't intiutive that SetQuery() was responsible for reading data off of the controller.

jpieper, 2023-08-24:
For now I added a comment in 1bb210fe8c8a06f496c66952715e3afd692ad318

Other potential names for that function all have various problems, although I welcome votes for alternatives.

Closed 2023-08-24.

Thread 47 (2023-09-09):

ASM encoder bit shift when using I2C

matthieuvigne, 2023-09-09:
As you have noticed it your commit 6ae66ef on July 23rd, the AS5048B/AS5600 encoders have a 2-bit shift in the I2C registers: 0XFF holds only 6 LSB, while 0xFE hold the other bits.

Previous versions of the firmware (on which my fork was based) did not include this bit shift, so I corrected it to:
```c++
    status->value =
        (encoder_raw_data_[4] << 6) |
        (encoder_raw_data_[5]);
```

This way, I get the 14-bit raw value of the encoder (i.e. one turn goes from 0 to 16384) ; the upper 2 bits of the uint16_t are set to zero.

I initially planned on opening a PR for this bugfix, but then I noticed that on 6ae66ef you modified this to:

```c++
    status->value =
        (encoder_raw_data_[4] << 8) |
        (encoder_raw_data_[5] << 2);
 ```

This means that you chose the have the lowest 2 bits at 0 - in other words, this encoder goes from 0 to 65536 by increments of 4. Was this done on purpose, i.e. do you want to fake a 16-bit encoder when the hardware only has 14 bits ? Or is this a mistake ?

jpieper, 2023-09-09:
The intent was to have it use the 16 bit range.  That shouldn't be a problem, as long as the CPR is configured correctly.

matthieuvigne, 2023-09-09:
Ok makes sense thanks. To be honest I find it a bit weird to configure a cpr at 16 bits for a 14 bits encoder, but as you say it all works perfectly fine, so I guess in the end it's just a question of taste.

Closing this issue.

jpieper, 2023-09-09:
Agreed it doesn't make the most sense... when I first implemented support I thought it reported a 16 bit value.  Now changing it would require adding upgrade logic in moteus_tool so as to not break systems on fw upgrade, which doesn't seem worth it.

Closed 2023-09-09.

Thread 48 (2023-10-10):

Use hardware trigger for ADCs

qosch, 2023-10-10:
I read your blog post on the STM32G4s ADC issue. Great work!
Did I get that right, that triggering the ADCs at exactly the same time would fix the issue?
In that case, there are hardware connections that can be used to trigger ADCs from timer update events (or some other timer events ). See Reference Manual Chapter 11.3.2, 21.4.18 and 28.3.31.

jpieper, 2023-10-10:
I did implement a hardware trigger based fix, but didn't deploy it because the current software fix was easier to manage and as effective so am sticking with it for now: 4db361035ac5adc999769b530727a5067b6d457b

Closed 2023-10-10.

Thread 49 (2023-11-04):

Cross-platform Builds

mawildoer, 2023-11-04:
Hi Josh,

Great looking project I'm trying to get my teeth into!

I've been running into a few issues building this on OSx, but reading through mainly the Bazel configs, I see only a handful of places which we will likely need to append to to make it work.

I expect if I can figure out how to make this work on OSx, we'll likely be able to do the same for Linux as well.

I'm gonna keep at it and see how far I can get

## What I've found so far

### 1

Off the bat, executing even `bazel --help` from the workspace causes the following error:
```
(.venv) moteus % bazel --help
Traceback (most recent call last):
  File "/Users/mattwildoer/Projects/mjbots/moteus/tools/bazel", line 107, in <module>
    main()
  File "/Users/mattwildoer/Projects/mjbots/moteus/tools/bazel", line 102, in main
    os.execv(bazel_bin_loc, ['bazel', ] + sys.argv[1:])
OSError: [Errno 8] Exec format error
```

At surface level, it seems like `tools/bazel` achieves the same thing as [bazelisk](https://github.com/bazelbuild/bazelisk)?
Seems like a pretty old script and I'm wondering if it's still required?

### 2

I see Windows-only deps here: https://github.com/mjbots/moteus/blob/1f4a19554a2b99578cdf566ec5172ee7ddc8304f/WORKSPACE#L36-L49

I notice the place it's forked from has doubled in commits since it was forked to `mjbots` and appears to support Windows, Linux and OSx: https://github.com/grailbio/bazel-toolchain/blob/master/platforms/BUILD.bazel#L34

Is there anything critical we'd miss by moving back to it?

jpieper, 2023-11-05:
The only thing you can compile in this repo is the firmware and its tests.  Unfortunately, that is only supported on x64 Ubuntu.  Windows and OS X are not supported host platforms for firmware compilation.  If you need to compile custom firmware, you can use a VM image.  However, pre-compiled releases are available in github, so most people don't ever need to compile the firmware.

thestumbler, 2023-11-05:
I'll ditto Josh's reply. I went down that path last year and gave up. I concluded that if I knew enough about Bazel, and I *really* wanted to run it on a Mac, I could have eventually solved it -- maybe. But that didn't apply in my case and it was easy enough to build firmware on an Ubuntu system, either VM (like parallels) or a separate machine.

I only did this briefly to experiment with some non-standard baud rates, but in the end I solved my CAN FD baud issues and used stock firmware.

mawildoer, 2023-11-05:
Oh, that's totally fine! I'm more than happy to use ubuntu in a docker container or the likes! I just thought it worked on Windows-only and wanted to fix that.

Did I perhaps miss some docs on "building firmware", or is the code the docs for how to build that?

jpieper, 2023-11-05:
https://github.com/mjbots/moteus/blob/main/docs/reference.md#flashing-and-building-firmware

mawildoer, 2023-11-05:
Sleeping on it, I came up with another approach which I hope can help others get off the ground quickly: https://github.com/mjbots/moteus/pull/50

Closed 2024-08-01.

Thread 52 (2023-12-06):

can moteus run on a MIT  compatible  hardware

yushun06, 2023-12-06:
I bought a MIT compatible motor which could run directly on https://github.com/bgkatz/motorcontrol.

I think moteus use the same chips such as 5027p, drv8323, stm32.

Can i just modify some pin def and use moteus on this hardware?

jpieper, 2023-12-06:
Sadly no.  moteus relies on the features of the STM32G4 controller, which is not compatible with the chips used on Ben Katz controllers.

Closed 2023-12-06.

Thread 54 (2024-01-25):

Itnis suport pmsm motor with 220v for step/dir interface?

artayasa, 2024-01-25:
It is suport step/dir interface wirh 220v pmsm mptor 2000ppr encorder sir?

jpieper, 2024-01-25:
Sadly no.  The specifications for each of the mjbots controllers can be found at mjbots.com, and no controllers support a step/dir interface.

Closed 2024-01-25.

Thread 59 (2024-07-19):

Moteus GUI Segfaults

kylevernyi, 2024-07-19:
I am trying to run the moteus_gui / tview tools to connect to my moteus-c1 for the first time. I am following the instructions of the getting started [video here](https://www.youtube.com/watch?v=6prAv9hbmeM&t=164s).

I am running Fedora 40. I ran the `pip3 install moteus-gui` command successfully. When I run `python3 -m moteus_gui.tview` command I get the following seg fault:

`[1]    8384 segmentation fault (core dumped)  python3 -m moteus_gui.tview`

I tried running gdb with `gdb --args python3 -m moteus_gui.tview`. I have attached the backtrace. [backtrace.txt](https://github.com/user-attachments/files/16315248/backtrace.txt) I put it into chatGPT and got the following which may or may not be correct:

> The stack trace indicates that the segmentation fault occurs when Python is trying to call the PyType_Ready function with a NULL type pointer. This suggests that there is a problem with the initialization of a Python type object, possibly due to an issue with the shiboken6 library.

I reinstalled the shiboken6 library but it had no effect.

Thank you for the support.

jpieper, 2024-07-19:
Hi!  That is a known problem with pyside6.7.  The pip packages require a version older than 6.7, but it loos like Fedora 40 has pyside 6.7 as a system package which you may have installed through yum.   Are you familiar with using python virtual environments?  If so, as a workaround you could use one with site packages disabled.

```
python -m venv --no-site-packages venv
venv/bin/pip install moteus-gui
venv/bin/tview
```

jpieper, 2024-07-19:
For reference, the upstream bug we filed is: https://github.com/jupyter/qtconsole/issues/605

kylevernyi, 2024-07-19:
Wow thanks for the quick fix. I am running python3 so I had to change your command slightly to

`python -m venv venv`
`venv/bin/pip install moteus-gui`

Unfortunately PySide 6.6 was still installed in the venv for some reason. I did a manual update with

`pip install PySide6 --upgrade`

Confirmed with

`python -c "from PySide6 import __version__; print(__version__)"`

Got the output to be 6.7.2 which is what you mentioned needing.

Then I ran `tview`

And everything is working!

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

Thanks for the quick help. Looking forward to using these controllers. We are building a satellite simulator in my lab and are using these for the gyroscopes.

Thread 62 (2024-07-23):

Moteus R4.11 uses a linear incremental encoder to control the timing timeout of linear motor calibration

away12356, 2024-07-23:
@jpieper

jpieper, 2024-07-23:
moteus does not currently support linear motors at all.

Is this a feature request?

away12356, 2024-07-23:
Can it only be used for rotating motors？

jpieper, 2024-07-23:
Correct, only rotating motors.

The firmware and tools are open source, so you could implement support yourself.  If you did so, you would certainly be welcome to share any results back, but it isn't required.

away12356, 2024-07-25:
Hi Josh,
How to use the can send command? Display ERR unknown command on tview
![Uploading 屏幕截图 2024-07-25 105910.png…]()

away12356, 2024-07-25:
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

away12356, 2024-07-25:
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

away12356, 2024-07-25:
@jpieper

Closed 2024-07-25.

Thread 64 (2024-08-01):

Questions about positioning performance with a moteus controller

away12356, 2024-08-01:

jpieper, 2024-08-01:
I'm unsure exactly what you are asking.  If the question is just how to use one of the moteus client side bindings from within a QT program, then there are several options.

First, you could use the python bindings along with the `asyncqt` library like tview does:

* https://github.com/mjbots/moteus/blob/main/utils/gui/moteus_gui/tview.py
* https://pypi.org/project/asyncqt/

Second, on linux or mac you could use the C++ bindings in either blocking or async mode.  One example (not developed or endorsed by mjbots) is here:

* https://github.com/georgevargas/GUI-APP-for-Moteus-Motor-Control

Does that answer your question?

away12356, 2024-08-01:
Is the minimum accuracy of Moteus position control 0.0036

jpieper, 2024-08-01:
The resolution of the onboard encoder is 14 bit, which works out to 0.000061 revolutions or 0.0219 degrees.  However that is only the resolution and not the accuracy.  In practice it has around 11-12 bits of precision depending upon your magnet mounting.  A rule of thumb is that position control needs about 16 counts of actual resolution of the encoder for typical loads.  That would result in a practical position control accuracy using the onboard encoder of around 1.4 degrees or 0.0039 revolutions.

The position control accuracy largely depends upon the encoder used.  If you have a more precise external encoder, then moteus can control position to an accuracy dependent upon that encoder using the above rules of thumb.

away12356, 2024-08-01:
What is the maximum resolution supported by Moteus?

jpieper, 2024-08-01:
The supported encoder with the current highest resolution is the 22 bit AksIM-2.  Internally, the position is tracked as a fixed point value with 32 bits of resolution per revolution as measured at the output.

away12356, 2024-08-01:
Do you recommend a high-resolution magnetic encoder

jpieper, 2024-08-01:
The encoder to use depends entirely on your application.  In many applications, the onboard encoder of moteus is sufficient.  Do you have any specific requirements you are targeting?

away12356, 2024-08-01:
The precision requirement for position control is relatively high, and it needs to be controlled very stably

away12356, 2024-08-01:
In practical applications, it has been found that the position control is not very stable when using onboard encoders

away12356, 2024-08-01:
The load is an optical instrument, which is hit on a mirror surface with a laser, causing significant shaking of the light spot

away12356, 2024-08-01:
Resolution 0.0001 degrees

jpieper, 2024-08-01:
None of the absolute encoders supported by moteus currently will be able achieve that resolution.  The 22 bit AksIM-2 has only around 0.0001 degree of resolution (I don't know its effective accuracy, but it is almost certainly worse), and as mentioned above you will need at least 16 counts of actual accuracy to achieve position control.

If you found a quadrature encoder with appropriate resolution, you might be able to use it on a moteus-n1 or moteus-c1 with the hardware quadrature inputs, however experimentation would be required.

Unfortunately, I don't have any specific encoder to recommend which can achieve your requested accuracy.

away12356, 2024-08-01:
Can incremental encoders be used

away12356, 2024-08-01:
What is the maximum number of bits supported by an incremental encoder?

Closed 2024-08-06.

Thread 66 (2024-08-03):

runtime error

Chetanyadav03, 2024-08-03:
while running the moteus BLDC motor with the r4.11 controllor(moteus), the calibration process showed an error for runtime, saying the firmware doesnot support the direction of the Motor. The exact error is:
RuntimeError: Requested motor direction not possible with current firmware version
What can be done to remove this error, it worked few hours earlier, but stopped working as i updated my windows

jpieper, 2024-08-03:
You can additionally pass `--cal-invert` to the calibration command or upgrade the firmware of your moteus.

Chetanyadav03, 2024-08-03:
Can u please guide on how to upgrade the firmware for the moteus controller

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

jpieper, 2024-08-03:
https://github.com/mjbots/moteus/blob/main/docs/reference.md#flashing-over-can

jpieper, 2024-08-04:
Was that enough to get your firmware updated?

Note, that passing `--cal-invert` is an equally fine option.

Chetanyadav03, 2024-08-04:
Yes it worked... Thanks a lot for your help... Before this I wasted like 3
hrs trying to rectify it but after your help it took about 10 minutes ...
👍🏼

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

jpieper, 2024-08-04:
Great!

Closed 2024-08-04.

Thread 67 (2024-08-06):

What command is sent in the original CAN from POS 1 0 nan v1 a1?

away12356, 2024-08-06:

away12356, 2024-08-07:
Thank you very much, the problem has been resolved

away12356, 2024-08-07:
Hello, how to solve timeout after running

jpieper, 2024-08-07:
You can clear faults by sending a stop command.

To avoid the fault in the first place, you can either send commands faster than the configured watchdog timeout:

https://github.com/mjbots/moteus/blob/main/docs/reference.md#servodefault_timeout_s

Or change or disable the timeout.

jpieper, 2024-08-10:
I'm going to mark this as closed now since there seem to be no further questions.

Closed 2024-08-10.

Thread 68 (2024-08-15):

Can Moteus work at -45 ° C-100 ° C

away12356, 2024-08-15:

jpieper, 2024-08-15:
All components on the board are rated at least -40C to 85C, however the board does not have rated temperature bounds. Any requirements would need to be evaluated in a specific application.

thestumbler, 2024-08-15:
One issue with plastic packages ICs at extremely cold temperatures is that the coefficient of expansion is different between the plastic material and the internals of the chip. As a result one main failure mode is that the internal lead wires can pull apart. At least this is what I was told as a young engineer. I’m not 100% if that logic applies to BGAs or not, but I would be hesitant to tempt fate.

This is one reason military and other high reliability projects use ceramic packages, because those are able to perform down to -55° (I don’t know what makes those fail below that point). That’s why many ICs used to be available in either plastic or ceramic packages, but that’s not a given anymore.

And Josh is correct in that having suitably rated ICs and other components is necessary but not sufficient to rate a board over a certain temperature range. Other factors like the PCB design and assembly, heat sinking, etc., are important as well. You’d probably want to conformal coat a board that goes down to -45 also, I’m thinking about moisture getting under a chip and freezing, for one example.

jpieper, 2024-08-22:
I'm going to consider this concluded given the lack of response.

Closed 2024-08-22.

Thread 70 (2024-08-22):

Motor calibrates but will not move.

robo-todd, 2024-08-22:
We have had great luck using the Moteus r4.11 controllers thus far with your default motor. We're moving on in our project to using a wide variety of different motors. Currently we're bringing up various FlipSky motors like a 6384/190kv motor.

The calibration procedure generates a calibration for the motor and I can even use the "d pwm" command to cause it to move, but position mode does nothing. It does not even seem to *try* to move the motor at all whereas your default motor just worked.  Any thoughts on how to get things moving again. These motors have a lot of cogging torque for sure. Suggestions?

I'm attaching
[flipsky.txt](https://github.com/user-attachments/files/16711453/flipsky.txt)
  the output of the default calibration which seems to work / behave pretty much the same on your default motors as this motor.

jpieper, 2024-08-22:
If the motor does not move you need to look at the reported mode and fault.  In tview, they are the first two entries in the `servo_stats` tab.

Fault decodings can be found here: https://github.com/mjbots/moteus/blob/main/docs/reference.md#0x00f---fault-code

jpieper, 2024-08-22:
Oh, and if you're integrating a bare controller for the first time, you might want to look through the points in the getting started guide: https://github.com/mjbots/moteus/blob/main/docs/getting_started.md including the configuration options you will likely want to ensure are usable.

robo-todd, 2024-08-22:
Thank you. So I'm getting fault 39, but I thought that I set the position limits and I did issue a stop command to reset mode, etc. It was strange because even "d brake" was not working.

Before you had answered I tried a few things like forcing the KV to the label on the motor, and then it seemed to work. I'm currently running an automatic config (not forced) and it is working as well, but on startup it had the fault 39. I'm going to try restarting a couple times (power cycle) just to see what's up.

Thanks for the quick response.

I see a lot of parameters for cogging_dq_comp and these are very high cogging torque motors. They are all zero after my default calibration. Is there a way to use those to smooth things out that I'm missing somewhere? I only see selecting higher or lower cal_bw_hz for this?

robo-todd, 2024-08-22:
OK... I forgot to save position limits in the calibration. It comes up with fault 39 basically every time because of that. Thanks for your answers.

Question on if I can optimize cogging torque comp still remains. I don't really see much in the reference or getting started on it (or I'm missing it).

jpieper, 2024-08-22:
If you are in a fault state, then the only command which will work is: `d stop`

You may have set the limits, but not issued a `conf write` to cause them to be stored to persistent storage?  If you restart tview, it will re-update all configuration parameters so you can see what is set now.

Cogging compensation is experimental.  I'd recommend getting things to work as well as you can before messing with it: https://docs.google.com/document/d/1M4O-LVki03qonNTkydv1N8gRteGIZk3ZyHd-mBpxL-U/edit#heading=h.x1qddq7g5cts

jpieper, 2024-08-22:
Checking in to see if you're all set here?  If so, I can close this ticket out.

robo-todd, 2024-08-22:
Yes. All good here. Was user error on saving position limits.

jpieper, 2024-08-22:
Great, thanks!

Closed 2024-08-22.

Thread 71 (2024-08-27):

Preventing Motor Stalling

kylevernyi, 2024-08-27:
Greetings. I am using a Moteus C1 to control some BLDC motors (as one does). I have noticed that the motor will sometimes stall at higher speeds (there is no load on the motor shaft). Is there some settings which I can tune to reduce this stalling? The motor sounds and looks as though it is getting caught over and over on the same spot. It is smooth at lower RPMs. The only settings I have changed are max current (10A) and max velocity (NaN) but I believe I am not close to max speed of the moteus.

I am experiencing stalling around 50-60 rad/sec. Also, stalling is more command when accelerating from a very low speed to a high speed.

Thanks,
Kyle

jpieper, 2024-08-27:
The most likely problem is an insufficient encoder bandwidth, but other problems are possible.  What motor are you controlling and what encoder are you using for commutation and output sensing?

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
jpieper, 2024-08-27:
Also, given that moteus reports all velocities in revolutions per second, do you mean Hz, or actually rad/s?

kylevernyi, 2024-08-28:
I am using the magnetic encoder built into the board with a diametric magnet.

Interesting,  I did not know that about the units. In the documentation under the velocity command, when it says

"When in Position mode, advance the desired position at the given velocity in Hz."

 does that mean that the velocity command should have units of Hz?

jpieper, 2024-08-28:
Yes all positions are reported and commanded in revolutions and all velocities are reported and commanded in revolutions per second, or Hz.

What motor are you controlling?

Can you try recalibrating with `--cal-bw-hz 200` ?

jpieper, 2024-09-14:
Were you able to get this to work?

kylevernyi, 2024-09-20:
Hello, I had some units mismatched and was sending some speeds that were unreasonable for my physical system. I have solved this and it is working very well now thank you.

Closed 2024-09-20.

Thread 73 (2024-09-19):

drv8323

away12356, 2024-09-19:
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

jpieper, 2024-09-19:
The uvlo fault indicates an undervoltage on the input. That can happen if moteus draws more power than your supply can provide.

jpieper, 2024-09-19:
If you need to operate with a constrained supply, you can always configure the `servo.max_power_W` to be lower.  Note that you may also need to then lower `servo.default_accel_limit` so that the velocity control loop continues to track well.

away12356, 2024-09-21:
Is there a command for relative position

away12356, 2024-09-21:
I want to turn 120 degrees in the previous position

jpieper, 2024-09-21:
There is not a single command.  You can either:

1. Query the position, add 0.33333 to it, then send that command.

2. Force the reported position to 0 then command 0.33333, like:

```
d exact 0
d pos 0.33333 0 nan
```

away12356, 2024-09-21:
thank you

Closed 2024-09-21.

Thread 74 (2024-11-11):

How to maximize the output stall torque when the motor is stall

away12356, 2024-11-11:

jpieper, 2024-11-11:
Unless you provide a command specific torque limit, are operating near the thermal limit, or have decreased the configurable maximum power or maximum current limit, moteus already applies the maximum torque possible.

An invalid calibration, caused by a poorly secured magnet or magnet that has exceeded its operating temperature, can also limit torque.  You could confirm that was the problem if calibrating the motor resolved the issue.

Can you provide any more context?

away12356, 2024-11-11:
When stall, the maximum output torque of the motor is 1.5N · m and the current is 6A. Is there any way to increase the output torque

jpieper, 2024-11-11:
What motor are you using, what are its specifications, and what input supply voltage are you using?

jpieper, 2024-11-11:
And where are you measuring current?

away12356, 2024-11-11:
PMSM, input voltage 24V

away12356, 2024-11-11:
Measure the current at the input end

jpieper, 2024-11-11:
What is the Kv, and winding resistance of your motor?

away12356, 2024-11-11:
Kv: 16.03763626929022
winding resistance: 2ohm

jpieper, 2024-11-11:
The Kv value looks like it was measured by moteus.  Was the winding resistance measured by moteus, or is it the nameplate number?

jpieper, 2024-11-11:
Thanks!  I would expect moteus to be able to apply approximately 11A of phase current to that motor with a 24V supply, which should result in about 6Nm of torque, assuming the motor does not become magnetically saturated.  I will say that your reported Kv rating is abnormally low for motors I have seen.

Is your motor an off the shelf motor?  Can you provide a link?  Does it have a nameplate peak or continuous torque rating?

Can you share a screenshot of tview when maximum torque is being generated?  I would like `servo_stats` expanded, the bottom command window included in the screenshot, and `servo_stats.torque_Nm` plotted on the left axis and `servo_stats.q_A` plotted on the right.

away12356, 2024-11-11:
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

jpieper, 2024-11-11:
In that plot, moteus reported that it generated a peak of 4Nm of torque.  Have you independently measured the torque and believe it to be only 1.5Nm instead of 4?

Also, from that plot it isn't clear what, if any were limits were reached during that process.  Can you share a screenshot of tview showing the telemetry tab with `servo_stats` while the maximum torque is being produced?

Finally, I'll repeat my question of if the motor you are using is off the shelf.  If so, can you provide a link?  Does it have a nameplate continuous or peak torque rating?

away12356, 2024-11-11:
This motor was designed by ourselves

away12356, 2024-11-11:
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

jpieper, 2024-11-11:
Thanks, however I need to see the contents of `servo_stats` *while* the motor is outputting the peak torque, not after.

jpieper, 2024-11-11:
Actually, while I'm asking for more things, instead of plotting, `servo_stats.q_A`, can you plot `servo_stats.position` on the right axis during the test?

away12356, 2024-11-11:
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

jpieper, 2024-11-11:
Thank you.  In this plot moteus claims it is drawing about 340W of power from your supply and the voltage of your supply has sagged to 22V, possibly from resistive losses between your PSU and the controller.

It looks like you are at, or near several different limits.

I believe the limit you are hitting right now is likely the phase modulation limit, which is derived from your supply voltage and phase resistance.

However, even you increased your supply voltage, you are very close to the electrical power limit of the moteus-r4, so you would not be able to increase the current or torque very much more, probably only by about 15% more before you hit the electrical power limit of moteus-r4.

moteus-n1 has a higher electrical power limit of 1200W, although the default in config is still 450.

Thus, if you want to get more torque out of this motor with a moteus controller, I would recommend increasing your supply voltage to 36 or 48V and use a moteus-n1 with `servo.max_power_W=1200`.  You are likely to still be limited by the maximum power rating of the moteus controller, but it will at least be a higher limit.

Note, that this maximum power limit will become more constraining if you are moving at non-zero speed, and if you need to achieve this maximum torque at non-zero speed it may not be practical to use a moteus controller with this motor.

away12356, 2024-11-11:
Can I increase the voltage to 44V

jpieper, 2024-11-11:
You can increase the voltage from 24V.  For moteus-r4, the 44V rating is the absolute maximum.  You will likely need to leave some margin to handle transients that result from regenerative braking at a minimum.  See: https://github.com/mjbots/moteus/blob/main/docs/reference.md#regenerative-braking-safety

As mentioned though, with the moteus-r4 and this motor, I expect you will hit the maximum power limit with a voltage of even 36V, so going higher than that with a moteus-r4 adds no more performance but increases the risk of damage.

away12356, 2024-11-12:
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

away12356, 2024-11-12:
Why can't PWM reach all high or low values during stalling

jpieper, 2024-11-12:
Currently moteus has an approximately 90% maximum duty cycle, partially due to the need to sense current and partially due to waveform generation limitations.

away12356, 2024-11-13:
Does tview have the function of recording data

jpieper, 2024-11-13:
tview does not have a data recording feature.  One easy option is to make a python script that performs your action, then do something like this example to write the data to a CSV file: https://github.com/mjbots/moteus/blob/main/lib/python/examples/csv_output.py

jpieper, 2024-11-14:
The position achievable by moteus will depend upon the encoder used.  See this previous issue where you asked a similar question: https://github.com/mjbots/moteus/issues/64

away12356, 2024-11-15:
What is the maximum frequency that CANFD supports for sending data?
results = await c.set_position(position=pos, kp_scale=5.0,kd_scale=1.0, accel_limit=1.0, query=True)
This function will block 2ms, can it not be blocked

jpieper, 2024-11-15:
You can read about CAN-FD update frequency here: https://jpieper.com/2024/05/16/optimizing-moteus-command-rate/

The python library uses the python asyncio primitives.  You can use any of the facilities available in that library to manage concurrency: https://docs.python.org/3/library/asyncio.html

Closed 2024-11-18.

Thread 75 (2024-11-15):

T-Motor MN5008 Calibration

robo-todd, 2024-11-15:
Hello. We've been having great luck with your R4.11 controller on a huge variety of motors and we've come up against some T-Motor MN5008's KV170's in our design and they simply will not calibrate, even with forcing the KV and trying to set the number of poles, etc.  It gets through the encoder calibration, etc. but then fails on KV and even forcing KV the resulting setup will not spin the motor.

Any suggestions on how we can resolve this? First one of similar motor that didn't "just work" but we need them for our design, so I'm hoping there is a way around it.

jpieper, 2024-11-15:
Have you worked through the items in this post?

https://jpieper.com/2024/05/23/debugging-moteus-calibration-failures/

robo-todd, 2024-11-15:
The motors are completely free to spin when we're doing this but I've not increased the power. Soldering should be solid and this is common to about 10 motor/amp setups so I don't think we have soldering issue on all 10 (about 10 other setups we have soldered in the same way with different motors all worked just fine basically instantly). There are no encoder error complaints from cal and the metric gets down to about 20-22.

I can try higher power, but it does spin completely around/back during the encoder calibration part... but on Kv it just never makes the motor(s) move.

jpieper, 2024-11-15:
As mentioned in that document, encoder problems will often not report that there is an encoder problem.  There are 95% odds that your problem is with the sense magnet.  Can you read through that post and verify all the sense magnet things it mentions?

robo-todd, 2024-11-15:
Yes. Turns out it is a sense magnet problem. Our mechanical folks thought they had used the same parameters, but we found an issue. We're making a test jig for the setup to double check with our mounting hardware out of the mechanical loop. This is likely mechanical. I'll try to close the post with an update today/tomorrow on what we found out.

robo-todd, 2024-11-16:
Following up. We had misaligned the mount (laterally offset), The MN5008 calibrated fine after we checked it on a separate jig. Thanks for the quick responses!

Closed 2024-11-16.

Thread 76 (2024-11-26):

Can't the resolution of Moteus using incremental encoders exceed 200000

away12356, 2024-11-26:

jpieper, 2024-11-26:
Are you observing an unexpected behavior?  If so, please describe it.

away12356, 2024-11-26:
Manually rotate the motor quickly, with no change in CPR and a large amount of error data

away12356, 2024-11-26:
R11, I am using software orthogonal. How can I connect hardware orthogonal

jpieper, 2024-11-26:
With software quadrature, you are limited to roughly 100000 counts per second of motion, no matter what the resolution is.

Unfortunately, hardware quadrature is not supported on moteus-r4, only on moteus-c1 and moteus-n1.  With those boards and hardware quadrature, the limit is higher at roughly 10000000 counts per second.

away12356, 2024-11-26:
What is the difference between hardware orthogonality and software orthogonality

jpieper, 2024-11-26:
Software quadrature is implemented as a software interrupt, hardware quadrature uses a dedicated hardware decoder in the microcontroller.

away12356, 2024-11-26:
Is hardware orthogonal wiring the same as software orthogonal wiring

away12356, 2024-11-26:
硬件正交布线与软件正交布线相同吗？

away12356, 2024-11-26:
Hardware quadrature wiring is the same as software quadrature?

Closed 2024-11-28.

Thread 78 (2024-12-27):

Step and direction input

RepRapThailand, 2024-12-27:
Dear Sir,

Could you please provide step and direction input firmware as stepper motor?

Best Regards,

KK

jpieper, 2024-12-27:
Thanks for the request!

That certainly is a long standing feature request, and may happen someday, but it it's not likely to be soon.  I can point you to ODrive if you need step/dir input add their products support that.

Closed 2024-12-27.

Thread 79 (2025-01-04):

Question regarding C1 schematic

saosebastiao, 2025-01-04:
For background, I'm trying to write a custom firmware for your C1 hardware which I bought in may of last year. The board is silk screened with  r1.2, so I'm referencing the schematics from `/hw/c1/r1.2/`

I'm looking at the schematic and it looks like the DRV8323_MOSI is connected to pin PC13. I'm assuming the DRV8323 is using SPI3, as the PC10 and PC11 pins line up with the AF6 functions for SPI3_SCK and SPI3_MISO (page 75/236 of the datasheet). However, the datasheet says there is a SPI3_MOSI pin on PB5 or PC12, and there aren't any SPI functions for pin PC13.

Could it be that the DRV8323_MOSI connection is actually made on the PC12 pin? My guess is either the datasheet is wrong (completely possible from what I've seen with other microcontrollers) or the schematic has a typo. I know for a fact that the C1 works (thanks, it's pretty cool BTW), so I'm reasonably sure it actually is connecting with SPI3_MOSI. But I don't really know anything about PCB design, so I can't figure out if a mislabeled schematic could actually connect with the correct pin. Got any insights?

jpieper, 2025-01-04:
The schematic is correct as is the datasheet.  The moteus firmware uses software SPI to communicate with the DRV8323: https://github.com/mjbots/moteus/blob/a90b5c2917f3b1d2727f978469a30d74bc4e5dab/fw/drv8323.cc#L400

Closed 2025-01-04.

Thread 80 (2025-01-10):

Support for secondary encoder

gupta-divy, 2025-01-10:
I recemtly purchased a moteus c1 motor controller and MA600 breakout board. I am using the onboard encoder for motor as in the devKit and was hoping to use the aux2 with MA600 breakout as secondary encoder for another shaft rotation in my system. Is it possible with current firmware? Can I directly read the aux2 SPI for encoder reading. Currently, the GUI shows spi_pin_error for aux2 SPI with the MA600 encoder mounted.

Any suggestions to make the setup work in this config?

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

jpieper, 2025-01-11:
First, you can often get faster support in the mjbots Discord: https://discord.gg/W4hUpBb

Second, `spi_pin_error` means you have not configured pins for `aux2` which are compatible with a SPI sensor.  You should set

```
aux2.pins.0.mode 1  # spi
aux2.pins.1.mode 1  # spi
aux2.pins.2 mode 1  # spi
aux2.pins.3.mode 2  # spi_cs
```

Note, you will also need to `motor_position` if you want to use the SPI encoder for anything.

You can read more about this in the reference manual: https://github.com/mjbots/moteus/blob/main/docs/reference.md#encoder-configuration and in this video: https://www.youtube.com/watch?v=a3UA6yzzgkE

gupta-divy, 2025-01-13:
Thanks, setting the pin configuration worked!

Closed 2025-01-13.

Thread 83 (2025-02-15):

Error code 33

acastles91, 2025-02-15:
My c1 driver was working this morning but now it's not moving my motor and servo_stats.mode is fault 1 and the fault is code 33. I have another c1 driver attached to the same kind of motor, with the same configuration and the same power supply and that one works without a problem, what can I do?

jpieper, 2025-02-15:
Fault 33 means the gate driver has reported a fault.

https://github.com/mjbots/moteus/blob/main/docs/reference.md#0x00f---fault-code

In the best case, you have a transient under voltage caused by drawing more current than your supply can provide.  If the fault 33 is persistent, then the board is likely damaged electrically.

What power supply and motor are you using?  What was the system doing the last time it was working?

acastles91, 2025-02-15:
Thanks for the help! The power supply is the 24V provided with the development kit and the motor is a [57BLF01](https://www.act-motor.com/brushless-dc-motor-57blf-product/). The last time it was working the motor was doing this command:

d pos -5000 0 0.9 v30.0 a10.0

I was testing how fast I could get to move a sculpture that I'm designing.

jpieper, 2025-02-15:
Unfortunately, I don't have much help at the moment and am about to go afk for 8 hours, but I don't see any particular problem with that motor.

While you were running that command did the motor do anything unusual?

acastles91, 2025-02-15:
Thank you for the fast reply. No, the motor didn't do anything strange, it performed the command but then it didn't move again. Is it possible that the motor is over sized for the driver and damaged it? Because I have a similar setup, the sculpture I'm designing needs to motors and I wouldn't want to damage the other driver

jpieper, 2025-02-15:
There is no problem with the size of the motor.  If you haven't yet, you should configure flux braking per the deployment guidelines:

https://github.com/mjbots/moteus/blob/main/docs/reference.md#regenerative-braking-safety

That said, we would like to make it such that you can't damage the device even if flux braking is not configured properly.  I would like to try and reproduce your problem and can get you a replacement driver, but not until after our vacation, so the 24th. To get that started, can you send an email to info@mjbots.com with your order number?

In the meantime, do you have an estimate for how much inertia or mass you have on the motor?

jpieper, 2025-02-24:
We have tackled this via email.

Closed 2025-02-24.

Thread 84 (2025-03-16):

Its posible control by step/dir??

artayasa, 2025-03-16:
Good day mate, i terest with your project. I still loking for someone make a driver for ac servo and can drive by step dir. Is your project posible??
I have plenty ac servo drive from 110v u til 220v with 20bit encoder ABZ or 2000ppr ABZ, But without driver. just have some driver but without motor.

jpieper, 2025-03-16:
Unfortunately no, step/dir is not supported as a command source.

Closed 2025-04-11.

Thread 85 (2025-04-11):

Abnormal calibration

away12356, 2025-04-11:
Calibrating -
Initial metric: 1708.3828481377807
optimizing - metric=25.34327
Traceback (most recent call last):
  File "<frozen runpy>", line 198, in _run_module_as_main
  File "<frozen runpy>", line 88, in _run_code
  File "/home/bmr/.local/share/pipx/venvs/moteus/lib/python3.12/site-packages/moteus/moteus_tool.py", line 2288, in <module>
    main()
  File "/home/bmr/.local/share/pipx/venvs/moteus/lib/python3.12/site-packages/moteus/moteus_tool.py", line 2284, in main
    asyncio.run(async_main())
  File "/usr/lib/python3.12/asyncio/runners.py", line 194, in run
    return runner.run(main)
           ^^^^^^^^^^^^^^^^
  File "/usr/lib/python3.12/asyncio/runners.py", line 118, in run
    return self._loop.run_until_complete(task)
           ^^^^^^^^^^^^^^^^^^^^^^^^^^^^^^^^^^^
  File "/usr/lib/python3.12/asyncio/base_events.py", line 687, in run_until_complete
    return future.result()
           ^^^^^^^^^^^^^^^
  File "/home/bmr/.local/share/pipx/venvs/moteus/lib/python3.12/site-packages/moteus/moteus_tool.py", line 2280, in async_main
    await runner.start()
  File "/home/bmr/.local/share/pipx/venvs/moteus/lib/python3.12/site-packages/moteus/moteus_tool.py", line 2069, in start
    await self.run_action(target)
  File "/home/bmr/.local/share/pipx/venvs/moteus/lib/python3.12/site-packages/moteus/moteus_tool.py", line 2142, in run_action
    await stream.do_calibrate()
  File "/home/bmr/.local/share/pipx/venvs/moteus/lib/python3.12/site-packages/moteus/moteus_tool.py", line 1129, in do_calibrate
    cal_result = await self.calibrate_encoder_mapping(
                 ^^^^^^^^^^^^^^^^^^^^^^^^^^^^^^^^^^^^^
  File "/home/bmr/.local/share/pipx/venvs/moteus/lib/python3.12/site-packages/moteus/moteus_tool.py", line 1261, in calibrate_encoder_mapping
    return await self.calibrate_encoder_mapping_absolute(
           ^^^^^^^^^^^^^^^^^^^^^^^^^^^^^^^^^^^^^^^^^^^^^^
  File "/home/bmr/.local/share/pipx/venvs/moteus/lib/python3.12/site-packages/moteus/moteus_tool.py", line 1436, in calibrate_encoder_mapping_absolute
    raise RuntimeError(f"Error(s) calibrating: {cal_result.errors}")
RuntimeError: Error(s) calibrating: ['encoder not an integral multiple of phase, 0.37255632098305735 > 0.1']

jpieper, 2025-04-11:
See: https://jpieper.com/2024/05/23/debugging-moteus-calibration-failures/

away12356, 2025-04-12:
The optical encoder I use

jpieper, 2025-04-12:
Your most recent comment appears truncated.

Closed 2025-04-22.

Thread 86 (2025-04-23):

在构建过程中报告错误

away12356, 2025-04-23:
ERROR: no such package '@llvm_toolchain//': Unknown LLVM release: clang+llvm-10.0.0-x86_64-linux-gnu-ubuntu-16.04.tar.xz

jpieper, 2025-04-23:
What host operating system and version are you using?

away12356, 2025-04-24:
ubuntu22.04，moteus-20240520

jpieper, 2025-04-24:
Only x64 desktop with 20.04, 22.04, and 24.04 is supported.  My guess is that you are using a different architecture.

away12356, 2025-04-24:
x86_64

away12356, 2025-04-24:
amd64

jpieper, 2025-04-24:
Is this your first time attempting to compile?  Have you had success elsewhere?

jpieper, 2025-04-24:
That error I would expect if you were trying to build on 24.04 with that older version of the moteus source.  I would expect 22.04 to work though.  In any event, can you build the most recent version?

jpieper, 2025-04-24:
The first release version that supports building on 24.04 is 2024-010-29.  Support was added in this commit: https://github.com/mjbots/moteus/commit/ee4f6ac9c6391523876836fcf6f276411b7f3670

away12356, 2025-04-24:
I am using Ubuntu24.04 to build the latest version of motues. Error message:< builtin>: BazelWorkspaceStatusAction stable-status.txt failed: Failed to determine workspace status: Process exited with status 127
/bin/sh:  1:  tools/workspace_status.sh: not found， Why was this file successfully built when it was stored in the tools directory

jpieper, 2025-04-24:
Are you building from a git checkout?  That is the only supported method of building.

away12356, 2025-04-24:
ERROR: <builtin>: BazelWorkspaceStatusAction stable-status.txt failed: Failed to determine workspace status: Process exited with status 127
/bin/sh: 1: tools/workspace_status.sh: not found
Analyzing: target //:target (2 packages loaded, 0 targets configured)

FATAL: bazel crashed due to an internal error. Printing stack trace:
java.lang.UnsupportedOperationException: /mnt/hgfs/pro/moteus/bazel-bin (??????)
	at com.google.devtools.build.lib.unix.NativePosixFiles.symlink(Native Method)
	at com.google.devtools.build.lib.unix.UnixFileSystem.createSymbolicLink(UnixFileSystem.java:364)
	at com.google.devtools.build.lib.vfs.Path.createSymbolicLink(Path.java:483)
	at com.google.devtools.build.lib.vfs.FileSystemUtils.ensureSymbolicLink(FileSystemUtils.java:341)
	at com.google.devtools.build.lib.vfs.FileSystemUtils.ensureSymbolicLink(FileSystemUtils.java:292)
	at com.google.devtools.build.lib.buildtool.OutputDirectoryLinksUtils.createLink(OutputDirectoryLinksUtils.java:277)
	at com.google.devtools.build.lib.buildtool.OutputDirectoryLinksUtils.createOutputDirectoryLinks(OutputDirectoryLinksUtils.java:141)
	at com.google.devtools.build.lib.buildtool.ExecutionTool.createConvenienceSymlinks(ExecutionTool.java:814)
	at com.google.devtools.build.lib.buildtool.ExecutionTool.handleConvenienceSymlinks(ExecutionTool.java:745)
	at com.google.devtools.build.lib.buildtool.BuildTool.buildTargetsWithMergedAnalysisExecution(BuildTool.java:351)
	at com.google.devtools.build.lib.buildtool.BuildTool.buildTargets(BuildTool.java:173)
	at com.google.devtools.build.lib.buildtool.BuildTool.processRequest(BuildTool.java:510)
	at com.google.devtools.build.lib.buildtool.BuildTool.processRequest(BuildTool.java:478)
	at com.google.devtools.build.lib.runtime.commands.TestCommand.doTest(TestCommand.java:164)
	at com.google.devtools.build.lib.runtime.commands.TestCommand.exec(TestCommand.java:117)
	at com.google.devtools.build.lib.runtime.BlazeCommandDispatcher.execExclusively(BlazeCommandDispatcher.java:664)
	at com.google.devtools.build.lib.runtime.BlazeCommandDispatcher.exec(BlazeCommandDispatcher.java:244)
	at com.google.devtools.build.lib.server.GrpcServerImpl.executeCommand(GrpcServerImpl.java:573)
	at com.google.devtools.build.lib.server.GrpcServerImpl.lambda$run$1(GrpcServerImpl.java:641)
	at io.grpc.Context$1.run(Context.java:566)
	at java.base/java.util.concurrent.ThreadPoolExecutor.runWorker(Unknown Source)
	at java.base/java.util.concurrent.ThreadPoolExecutor$Worker.run(Unknown Source)
	at java.base/java.lang.Thread.run(Unknown Source)

away12356, 2025-04-24:
INFO: Analyzed target //:target (62 packages loaded, 22097 targets configured).
INFO: Found 1 target and 0 test targets...
Target //:target up-to-date:
  bazel-bin/fw/moteus.bin
  bazel-bin/fw/moteus.08000000.bin
  bazel-bin/fw/moteus.0800c000.bin
  bazel-bin/fw/moteus.08010000.bin
  bazel-bin/fw/can_bootloader.bin
INFO: Elapsed time: 900.149s, Critical Path: 14.27s
INFO: 439 processes: 3 internal, 436 processwrapper-sandbox.
INFO: Build completed successfully, 439 total actions
ERROR: No test targets were found, yet testing was requested

jpieper, 2025-04-24:
That looks like it was successful, you should be good to go.

away12356, 2025-04-24:
Thank you very much for your help

jpieper, 2025-04-24:
What boards do you have and which are produced by mjbots vs self produced?

away12356, 2025-04-24:
Can the latest version of mjbots' R4.11 program be used

jpieper, 2025-04-24:
Yes

away12356, 2025-04-24:
How to write UUID when downloading the program to a new board?

jpieper, 2025-04-24:
Unfortunately, mjbots only offers no-cost support to organizations that are exclusively using mjbots produced boards.  We do offer paid support options.  Send an email to info@mjbots.com for more information.

Closed 2025-04-24.

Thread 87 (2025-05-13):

I2C AS5600 Encoder and Digital Inputs

robo-todd, 2025-05-13:
We're working with the R4 and C1 controller boards and attempting to use AUX ports for connection to digital inputs (limit switches) and absolute encoders (AS5600 boards on I2C) and when we configure these things we get nothing back and see no activity.

Perhaps we're reading the pin mappings wrong for documentation, but we have tried a lot of permutations and see no activity on the pins and setting them to digital inputs for limits also never seem to get read (status panel of t-view for the port).

Any suggestions? We're getting nowhere and no configuration for aux2/aux1 seem to have any effect or result in any I2C activity or gpio input state being read.

For the R4 specifically:
In the I2C case we set the relevant aux2 pins (1 and 2) to be I2C function.
We set the I2C device 0 and its address and period, etc.
We get on clock activity and it doesn't seem to be accessing the AS5600 at all.
Changing pullup state has no effect?
We don't know what I2C "mode" means on the config and docs don't say... it is defaulted to "1".

In the digital input case we set the aux2 pins (1 and 2) to be digital input function.
Nothing is reflected in telemetry, etc.
Pullup state seems to have no effect

jpieper, 2025-05-13:
For the r4 I2C, you need to use pins 0 and 1, per the "I2C" disambiguator section of: https://jpieper.com/2022/06/30/flexible-i-o-worked-examples/

```
conf set aux2.pins.0.mode 13        # i2c
conf set aux2.pins.1.mode 13        # i2c
```

The moteus-r4 ABS pins have hard-wired 2.2k pullup resistors installed on the two pins, the pin specific pullups will have no effect for it.

Once you have set the correct pins, can you share a screenshot of your config and telemetry for `aux2` in tview?

Let's look at the digital inputs after you have I2C working.

jpieper, 2025-05-13:
You can also see the appropriate pin numberings to use in the "Aux" column of the pin table in the reference documentation: https://github.com/mjbots/moteus/blob/main/docs/reference.md#aux2--abs

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

robo-todd, 2025-05-19:
OK. Circling back to this.  Probably user error on our part, but we had to actively go in and disable the SPI setting and then our other settings worked just fine.  Maybe the documentation could make this default a little clearer? I would have thought that it would come out of the box in a kind of "everything disabled" mode for the aux ports. So that is what was throwing us off.

Once we disabled SPI things worked great. Thank you!

jpieper, 2025-05-19:
I'm glad you got things working.  The aux port SPI being configured by default is actually fixed in the most recent firmware.  In any event, the key thing is to look in the telemetry under aux1/aux2 for errors, which will tell you what is amiss.

Closed 2025-05-19.

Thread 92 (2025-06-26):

CAN-FD frames aren't properly padded

jbtheou, 2025-06-26:
I noticed an issue where when the format is adjusted on the fly, the behavior is unexpected (stall data is still sent).

Looking at the candump, noticed that the userspace is sending non-valid DLC

```
  can1  00008001  [22]  01 00 0A 0D 20 CD CC 4C 3F 0D 29 00 00 C0 40 11 00 11 0B 19 81 02
  can1       100  [16]  21 00 0A 21 0B 01 29 81 02 0B 01 00 00 50 50 50
  can1  00008001  [19]  01 00 0A 0D 20 CD CC 4C BF 0D 29 00 00 C0 40 11 00 11 0B
  can1       100  [06]  21 00 0A 21 0B 01
```

Looking at the code, I am not seeing any auto-padding logic for the requests. Is it expected? Am I missing the logic somewhere?

Thanks a lot

jbtheou, 2025-06-26:
Regarding the actual stall data issue, with a bit more data requested, if I stop requesting 0x101 (FW version), its still sent
```
  can1  00008001  [24]  01 00 0A 0D 20 CD CC 4C 3F 0D 29 00 00 C0 40 11 00 11 0B 11 0F 19 81 02
  can1       100  [16]  21 00 0A 21 0B 01 21 0F 00 29 81 02 0B 01 00 00
  can1  00008001  [21]  01 00 0A 0D 20 CD CC 4C BF 0D 29 00 00 C0 40 11 00 11 0B 11 0F
  can1       100  [16]  21 00 0A 21 0B 01 21 0F 00 29 81 02 0B 01 00 00
```
But I believe that due to the invalid DLC, the FW is reusing some stall data, that's why it's happening. So the DLC padding seems to be the main issue

jbtheou, 2025-06-26:
@jpieper Please let me know if you need additional information. Working on a fix on my end in //

jpieper, 2025-06-26:
What software and hardware are you using to send commands?

jpieper, 2025-06-26:
I mean, the wire format for CAN-FD doesn't even have a representation for a DLC of 19 bytes, so by definition moteus did not receive a frame with that length.

jpieper, 2025-06-26:
For reference, the python library rounds up to the nearest DLC here in the code:

https://github.com/mjbots/moteus/blob/d9a1b3505c91308036ffd905c0cecaa429a5d7e6/lib/python/moteus/fdcanusb.py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
https://github.com/mjbots/moteus/blob/d9a1b3505c91308036ffd905c0cecaa429a5d7e6/lib/python/moteus/pythoncan.py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

And the C++ library does so here:

https://github.com/mjbots/moteus/blob/d9a1b3505c91308036ffd905c0cecaa429a5d7e6/lib/cpp/mjbots/moteus/moteus_transport.h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

Although it looks like the C++ socketcan library does not currently round up.  Are you using the C++ client library?

(also, the firmware version register is largely meaningless and not worth requesting, as it is actually the "ABI version" not the firmware version)

jbtheou, 2025-06-26:
Exactly, and I think that's why the FW is catching some outdated data when parsing the memory.  Just using a customized example

```
// Copyright 2025 mjbots Robotic Systems, LLC.  info@mjbots.com
//
// Licensed under the Apache License, Version 2.0 (the "License");
// you may not use this file except in compliance with the License.
// You may obtain a copy of the License at
//
//     http://www.apache.org/licenses/LICENSE-2.0
//
// Unless required by applicable law or agreed to in writing, software
// distributed under the License is distributed on an "AS IS" BASIS,
// WITHOUT WARRANTIES OR CONDITIONS OF ANY KIND, either express or implied.
// See the License for the specific language governing permissions and
// limitations under the License.

/// @file
///
/// This example shows how to use Controller::SetPositionWaitComplete.

#include <signal.h>
#include <unistd.h>

#include <iostream>

#include "moteus.h"

void clean_routine(int s)
{
  using namespace mjbots;

  ::printf("\nCaught signal %d\n", s);
  moteus::Controller::Options options;
  options.id = 1;

  moteus::Controller controller(options);

  // Command a stop to the controller in order to clear any faults.
  controller.SetStop();

  exit(1);
}

int main(int argc, char** argv) {
  using namespace mjbots;

  /* Not a part of the header */
  constexpr uint16_t kFirmwareVersion = 0x101;

  /* Catch CTRL + C */
  signal(SIGINT, clean_routine);

  moteus::Controller::DefaultArgProcess(argc, argv);

  moteus::Controller::Options options;
  options.id = 1;

  // Only position and velocity are sent by default when sending
  // position mode commands.  If you want to send any other fields you
  // need to specify their resolution.  That can either be done here
  // in the `Controller::Options` structure, or on a per-command basis
  // using the format override argument.
  options.position_format.accel_limit = moteus::kFloat;

  /* We are not using velocity, we can ignore it */
  options.position_format.velocity = moteus::kIgnore;

  moteus::Controller controller(options);

  // When using the diagnostic protocol, it is important to know that
  // applications like tview may leave the controller "spewing" on the
  // diagnostic channel, i.e. sending unsolicited data.  In order stop
  // that, a client needs to issue a "tel stop" command, and then
  // flush all data that is present.  After that point, normal
  // commands can be issued.
  controller.DiagnosticWrite("tel stop\n");
  controller.DiagnosticFlush();

  // DiagnosticCommand will always return the result.  The `conf get`
  // diagnostic command is unique in that it replies with a single
  // line and no final "OK", so we use the `kExpectSingleLine` option.
  auto result = controller.DiagnosticCommand(
      "conf get servopos.position_max", moteus::Controller::kExpectSingleLine);
  if (result == "") {
    ::printf("Exiting because unable to get diag info (max).\n");
    return 1;
  }
  const auto pos_max = std::stod(result);

  result = controller.DiagnosticCommand(
      "conf get servopos.position_min", moteus::Controller::kExpectSingleLine);
  if (result == "") {
    ::printf("Exiting because unable to get diag info (min).\n");
    return 1;
  }
  const auto pos_min = std::stod(result);

  ::printf("Expected range: [%f,%f]\n", pos_min, pos_max);

  // Command a stop to the controller in order to clear any faults.
  controller.SetStop();

  moteus::PositionMode::Command cmd = {};
  cmd.accel_limit = 6.0;

  auto print = [](auto maybe_result) {
    if (maybe_result) {
      const auto r = maybe_result->values;
      const uint16_t reg = r.extra[0].register_number;
      if (reg == kFirmwareVersion) {
        const auto int_version = static_cast<int>(r.extra[0].value);
        ::printf("Firmware version 0x%x\n", int_version);
      } else {
        ::printf("%3d p/v/t=(%7.3f,%7.3f,%7.3f)  v/t/f=(%5.1f,%5.1f,%3d)   \r",
                 static_cast<int>(r.mode), r.position, r.velocity, r.torque, r.voltage, r.temperature,
                 r.fault);
        ::fflush(stdout);
      }

      if (r.mode == moteus::Mode::kFault || r.mode == moteus::Mode::kPositionTimeout) {
        ::printf("\n\nExiting because of fault %d/%d.\n", static_cast<int>(r.mode), r.fault);
        std::exit(1);
      }
    }
  };

  moteus::Query::Format custom_fmt;
  /* Initially, only care about the mode/fault for the initial position request
   * while requesting the FW version
   */
  custom_fmt.mode = moteus::kInt8;
  custom_fmt.position = moteus::kIgnore;
  custom_fmt.velocity = moteus::kIgnore;
  custom_fmt.torque = moteus::kIgnore;
  custom_fmt.voltage = moteus::kIgnore;
  custom_fmt.temperature = moteus::kIgnore;
  custom_fmt.fault = moteus::kInt8;
  custom_fmt.extra[0].register_number = kFirmwareVersion;
  custom_fmt.extra[0].resolution = moteus::kInt32;

  while (true) {
    cmd.position = pos_max - 0.2;
    print(controller.SetPositionWaitComplete(cmd, 0.001, nullptr, &custom_fmt));

    /* We want to ask the Firmware version once */
    if (custom_fmt.extra[0].register_number == kFirmwareVersion) {
      /* Restore the default queries for now */
      custom_fmt = {};
      custom_fmt.mode = moteus::kInt8;
      custom_fmt.position = moteus::kIgnore;
      custom_fmt.velocity = moteus::kIgnore;
      custom_fmt.torque = moteus::kIgnore;
      custom_fmt.voltage = moteus::kIgnore;
      custom_fmt.temperature = moteus::kIgnore;
      custom_fmt.fault = moteus::kInt8;
    }

    cmd.position = pos_min + 0.2;
    print(controller.SetPositionWaitComplete(cmd, 0.001, nullptr, &custom_fmt));
  }

  return 0;
}
```

```
  can1  00008001  [24]  01 00 0A 0D 20 CD CC 4C 3F 0D 29 00 00 C0 40 11 00 11 0B 11 0F 19 81 02
  can1       100  [16]  21 00 0A 21 0B 01 21 0F 00 29 81 02 0B 01 00 00
  can1  00008001  [21]  01 00 0A 0D 20 CD CC 4C BF 0D 29 00 00 C0 40 11 00 11 0B 11 0F
  can1       100  [16]  21 00 0A 21 0B 01 21 0F 00 29 81 02 0B 01 00 00
```

jpieper, 2025-06-26:
Want to try this patch?

```
diff --git a/lib/cpp/mjbots/moteus/moteus_transport.h b/lib/cpp/mjbots/moteus/moteus_transport.h
index dd45e2cd..95dcf421 100644
--- a/lib/cpp/mjbots/moteus/moteus_transport.h
+++ b/lib/cpp/mjbots/moteus/moteus_transport.h
@@ -285,6 +285,18 @@ class TimeoutTransport : public Transport {
   }

+  static size_t RoundUpDlc(size_t size) {
+    if (size <= 8) { return size; }
+    if (size <= 12) { return 12; }
+    if (size <= 16) { return 16; }
+    if (size <= 20) { return 20; }
+    if (size <= 24) { return 24; }
+    if (size <= 32) { return 32; }
+    if (size <= 48) { return 48; }
+    if (size <= 64) { return 64; }
+    return size;
+  }
+
  protected:
   virtual int CHILD_GetReadFd() const = 0;
   virtual void CHILD_SendCanFdFrame(const CanFdFrame&) = 0;
@@ -708,18 +720,6 @@ class Fdcanusb : public details::TimeoutTransport {
     tx_buffer_size_ = 0;
   }

-  static size_t RoundUpDlc(size_t size) {
-    if (size <= 8) { return size; }
-    if (size <= 12) { return 12; }
-    if (size <= 16) { return 16; }
-    if (size <= 20) { return 20; }
-    if (size <= 24) { return 24; }
-    if (size <= 32) { return 32; }
-    if (size <= 48) { return 48; }
-    if (size <= 64) { return 64; }
-    return size;
-  }
-
   static int ParseHexNybble(char c) {
     if (c >= '0' && c <= '9') { return c - '0'; }
     if (c >= 'a' && c <= 'f') { return c - 'a' + 10; }
@@ -828,8 +828,11 @@ class Socketcan : public details::TimeoutTransport {
       // Set the frame format flag if we need an extended ID.
       send_frame.can_id |= (1 << 31);
     }
-    send_frame.len = frame.size;
+    send_frame.len = RoundUpDlc(frame.size);
     std::memcpy(send_frame.data, frame.data, frame.size);
+    if (send_frame.len != frame.size) {
+      std::memset(&send_frame.data[frame.size], 0x50, send_frame.len - frame.size);
+    }

     using F = CanFdFrame;

```

jbtheou, 2025-06-26:
Works great! The issue is fixed and I am properly seeing the padding. Thanks a lot for the quick feedback here, very much appreciated

```
  can1  00008001  [24]  01 00 0A 0D 20 CD CC 4C 3F 0D 29 00 00 C0 40 11 00 11 0B 11 0F 19 81 02
  can1       100  [16]  21 00 0A 21 0B 01 21 0F 00 29 81 02 0B 01 00 00
  can1  00008001  [24]  01 00 0A 0D 20 CD CC 4C BF 0D 29 00 00 C0 40 11 00 11 0B 11 0F 50 50 50
  can1       100  [12]  21 00 0A 21 0B 01 21 0F 00 50 50 50
```

Closed 2025-06-26.

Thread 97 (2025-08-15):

GPIO pins won't enable

Elijah884, 2025-08-15:
Hello,

Whenever I try to enable the GPIO pins (either through register commands or diagnostic commands) they always remain in an off state. Blwo I have the output of gpio.py from the examples section of the moteus library, which shows all pins on the GPIO are set to 0:
root@shuttle1:~# python3 gpio_test.py
AUX1
  Pin 0 - 0
  Pin 1 - 0
  Pin 2 - 0
  Pin 3 - 0
  Pin 4 - 0

AUX2
  Pin 0 - 0
  Pin 1 - 0
  Pin 2 - 0
  Pin 3 - 0

From moteus.Controller.query()
AUX1
  Pin 0 - 0
  Pin 1 - 0
  Pin 2 - 0
  Pin 3 - 0
  Pin 4 - 0

AUX2
  Pin 0 - 0
  Pin 1 - 0
  Pin 2 - 0
  Pin 3 - 0
SocketcanBus was not properly shut down

Additionally, if I try to send a command to 5C to set it to 7F (enabling all gpio pins) the controller doesn't respond to that command and then states that all gpio pins are disabled when I read from 5C:
Sent:  00 01 5C 7F
Received:
Sent:  10 01 5C
Received:  20 01 5C 00

I'm not sure if I'm misinterpreting this or if there's some other setting I need to change first before enabling GPIO, but I've tried a few configurations and can't get it to work.

Thank you for your help!

jpieper, 2025-08-15:
I think error 12 means you have a SPI MA600 configured on the aux port but configuration was not successful. Can you share either the config dump, or it is easier if you can share a screenshot from tview with the config and telemetry.

jpieper, 2025-08-15:
And I should say, if there is any error, then nothing will work on that aux port. Thus you need to understand and resolve the error.

Elijah884, 2025-08-15:
Makes sense, I have pictures of the config and telemetry screens, sorry they aren't screenshots but scrot, print screen, and gnome screenshot all decided to not work

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

Elijah884, 2025-08-15:
I'm going to try it on Aux2 instead to see if I get that same error

jpieper, 2025-08-15:
What type of controller do you have?  I.e. is it a moteus-x1?  You have onboard MA600 configured on aux1, but only the moteus-x1 has an onboard MA600.

Elijah884, 2025-08-15:
I'm not sure what it means but in the telemetry it says <error:quad_pin_error:6>. Where do I find what these aux errors mean? I can't find them in the documentation anywhere.

jpieper, 2025-08-15:
Most of the aux errors mean you do not have compatible pins configured for the devices you have configured.  The quad pin error means that you do not have appropriate pins configured to be used for quadrature, but attempted to enable quadrature.

If you want to use quadrature input you need to first:

aux2.quadrature.enable = 1

Then configure which pins you want.  For instance, if you want to use the hardware enabled quadrature pins from: https://github.com/mjbots/moteus/blob/main/docs/reference.md#aux2--abs  you would set:

aux2.pins.2.mode 5  # hw quad
aux2.pins.3.mode 5  # hw quad

I will note that in your screenshots earlier your aux1.error was actually error 1, not error 12.  That is a SPI pin error.  I'm not entirely sure why you would have a SPI pin error when the onboard MA600 is configured.  However, an error 12 would easily happen if you had connected external circuits to the aux1 pins but had not disabled the MA600 by setting

aux1.spi.mode = 1 # disabled

All of this is of course much easier in tview where the various enumerations and status codes have their text strings shown.

You can learn about the pin and function configuration process by watching this video: https://www.youtube.com/watch?v=a3UA6yzzgkE  or reading this post: https://blog.mjbots.com/2022/06/27/flexible-i-o-auxiliary-port-configuration/

jpieper, 2025-08-19:
Have you ever calibrated a moteus controller successfully before?

Can you share a screenshot of the drv8323 tree?

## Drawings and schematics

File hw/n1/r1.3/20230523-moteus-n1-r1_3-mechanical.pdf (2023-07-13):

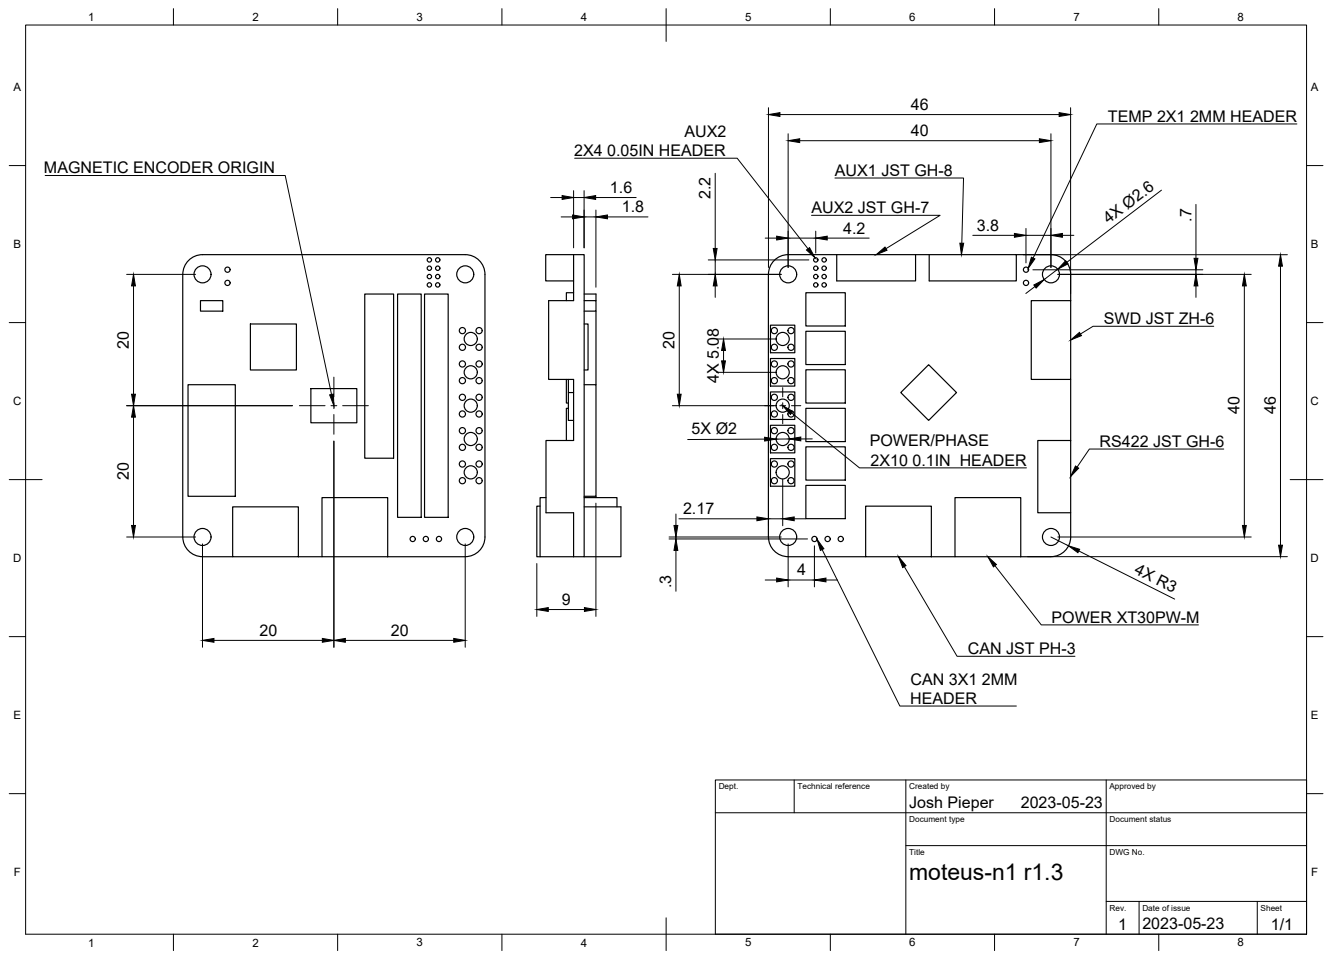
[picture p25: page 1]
Title; DWG No.; Rev.; Date of issue; Sheet; moteus-n1 r1.3; POWER XT30PW-M; AUX2 JST GH-7; AUX1 JST GH-8; RS422 JST GH-6 4X 5.08 20; POWER/PHASE; 2X10 0.1IN HEADER; 2X4 0.05IN HEADER .3; CAN 3X1 2MM; TEMP 2X1 2MM HEADER

MAGNETIC ENCODER ORIGIN

SWD JST ZH-6

CAN JST PH-3

Dept. | Technical reference | Created by Josh Pieper 2023-05-23 | Approved by

Document type | Document status

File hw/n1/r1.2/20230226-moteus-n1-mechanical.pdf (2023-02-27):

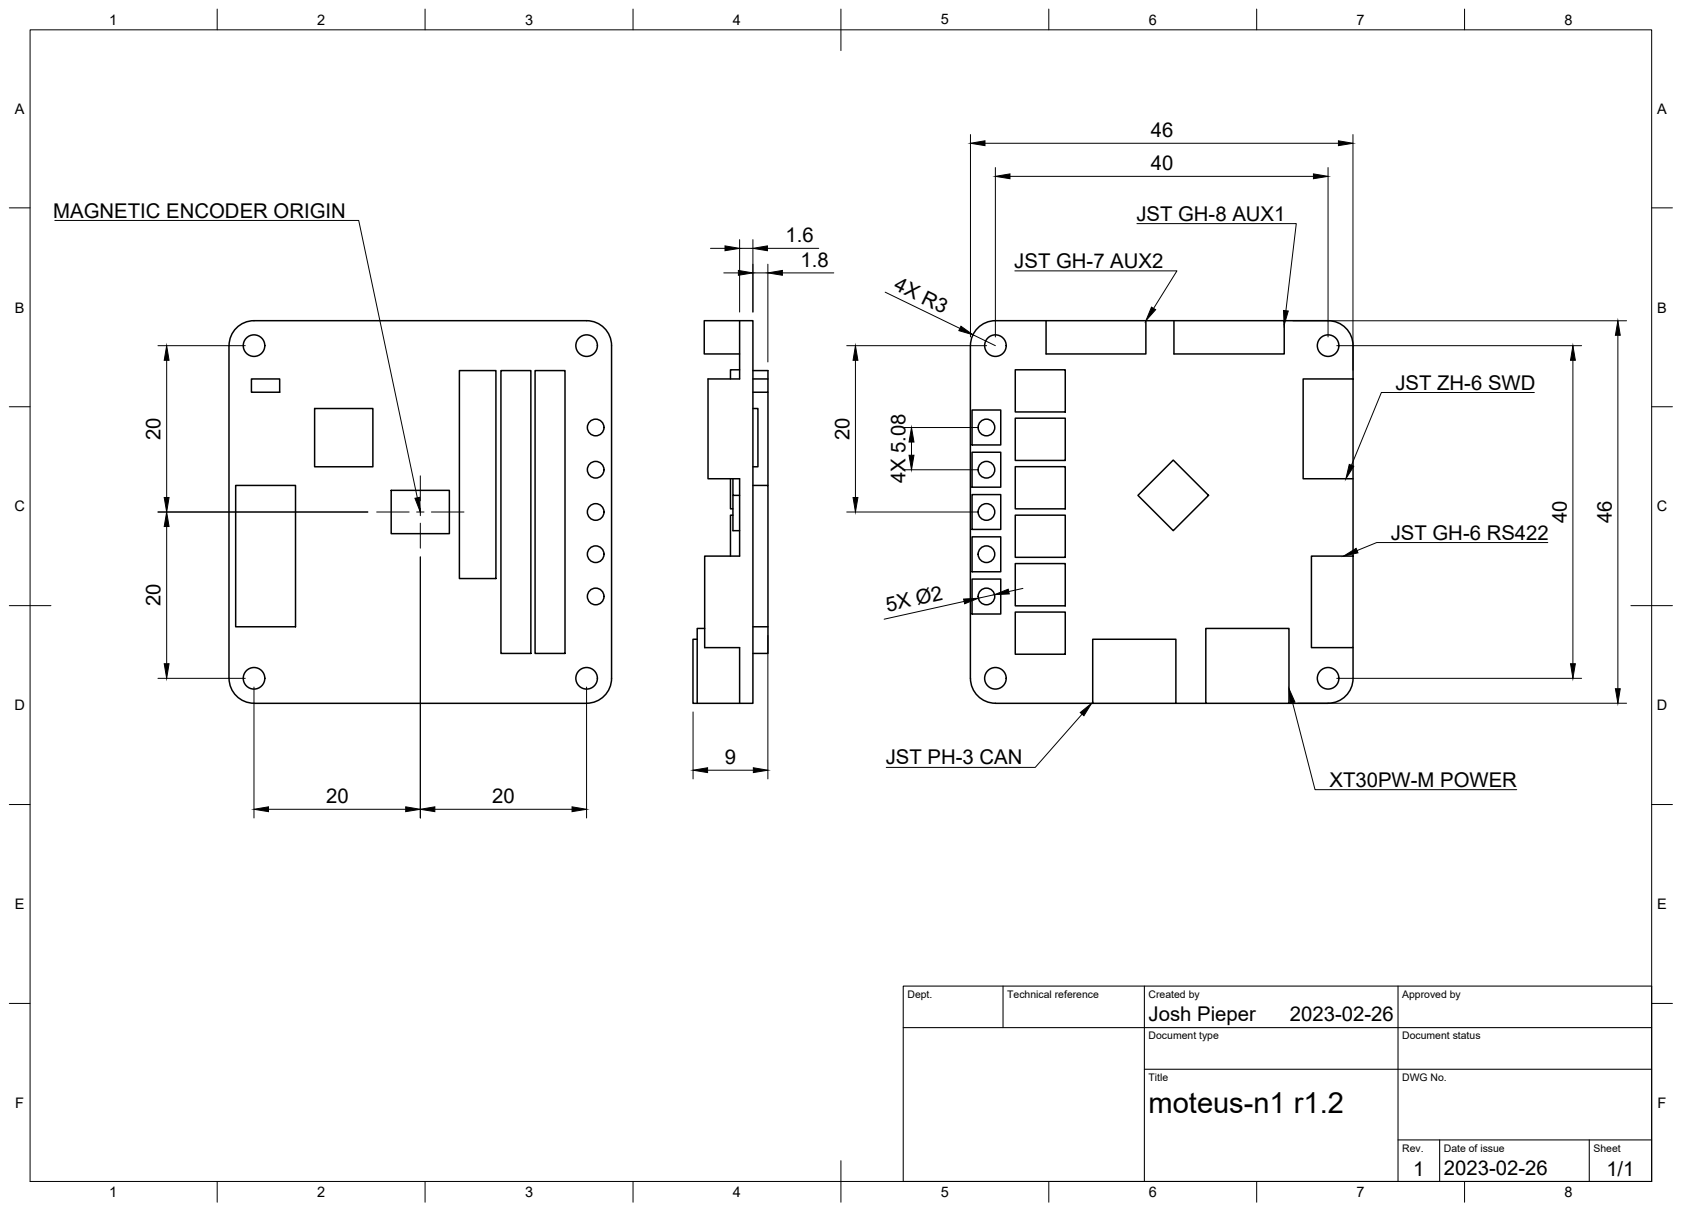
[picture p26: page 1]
Title; DWG No.; Rev.; Date of issue; Sheet; moteus-n1 r1.2; XT30PW-M POWER; JST GH-7 AUX2; JST GH-8 AUX1; JST GH-6 RS422 4X 5.08 20

MAGNETIC ENCODER ORIGIN

JST ZH-6 SWD

JST PH-3 CAN

Dept. | Technical reference | Created by Josh Pieper 2023-02-26 | Approved by

Document type | Document status

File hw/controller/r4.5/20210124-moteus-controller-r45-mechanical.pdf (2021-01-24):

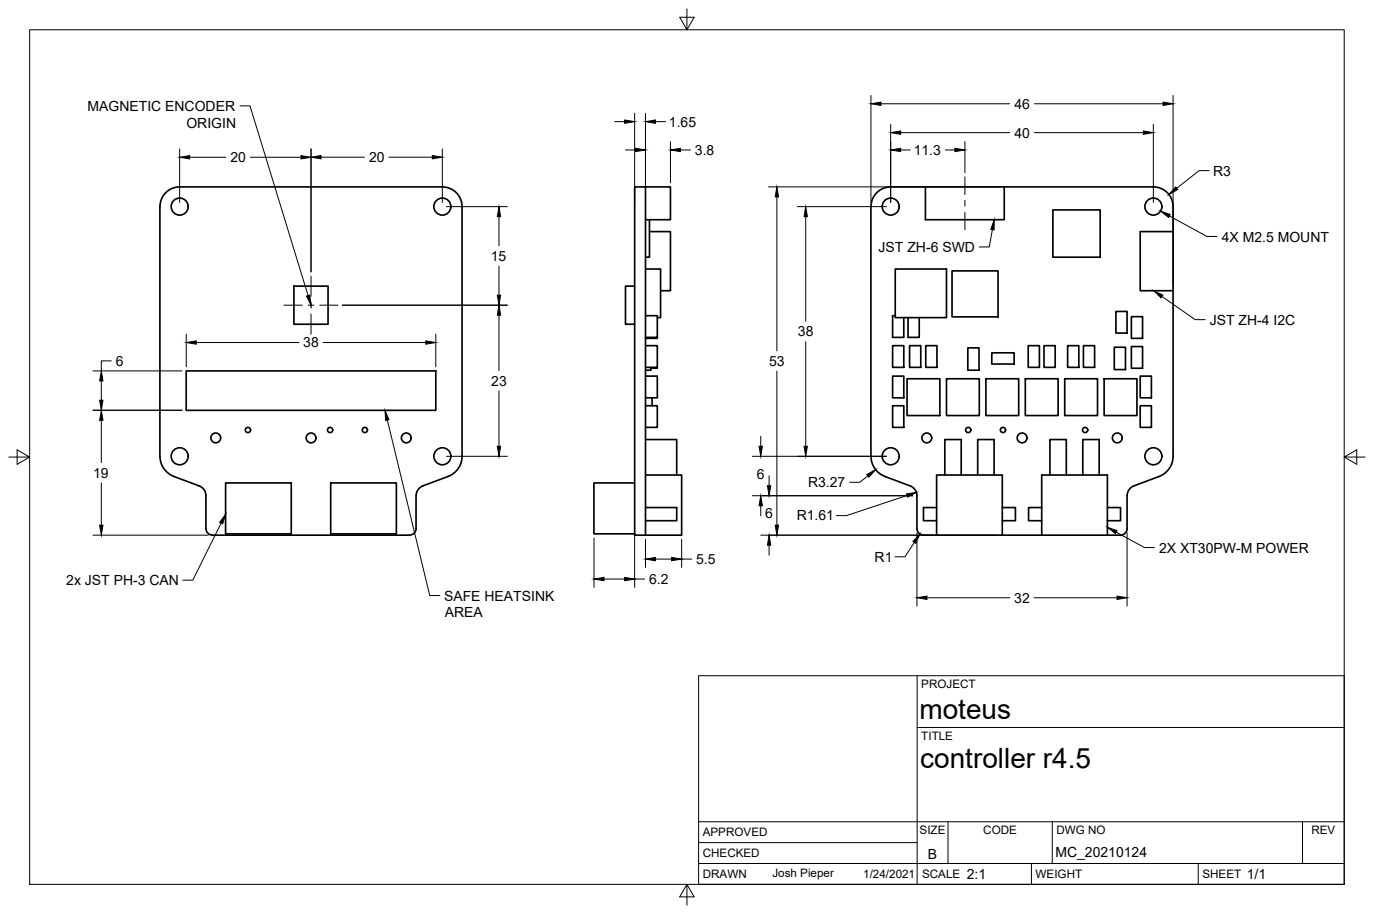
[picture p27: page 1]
SIZE; CODE; DWG NO; REV; Josh Pieper; controller r4.5; 4X M2.5 MOUNT; 2X XT30PW-M POWER; JST ZH-4 I2C; SAFE HEATSINK; MAGNETIC ENCODER

JST ZH-6 SWD

2x JST PH-3 CAN

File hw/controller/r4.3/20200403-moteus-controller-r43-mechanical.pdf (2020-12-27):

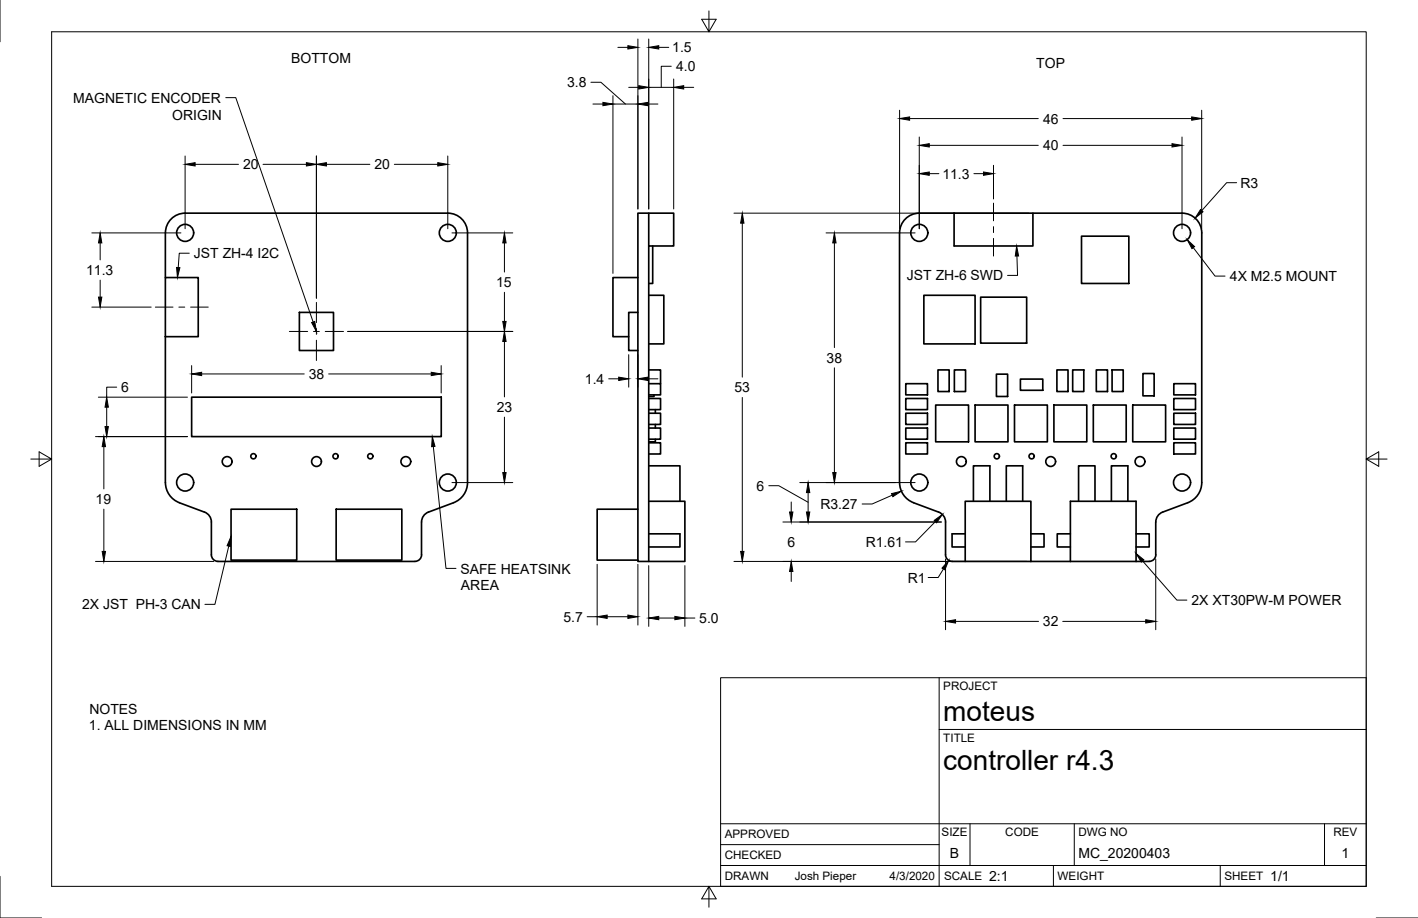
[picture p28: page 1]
SIZE; CODE; DWG NO; REV; Josh Pieper; controller r4.3; 4X M2.5 MOUNT; MAGNETIC ENCODER; 2X XT30PW-M POWER; JST ZH-4 I2C; SAFE HEATSINK

JST ZH-6 SWD

2X JST PH-3 CAN

NOTES
1. ALL DIMENSIONS IN MM

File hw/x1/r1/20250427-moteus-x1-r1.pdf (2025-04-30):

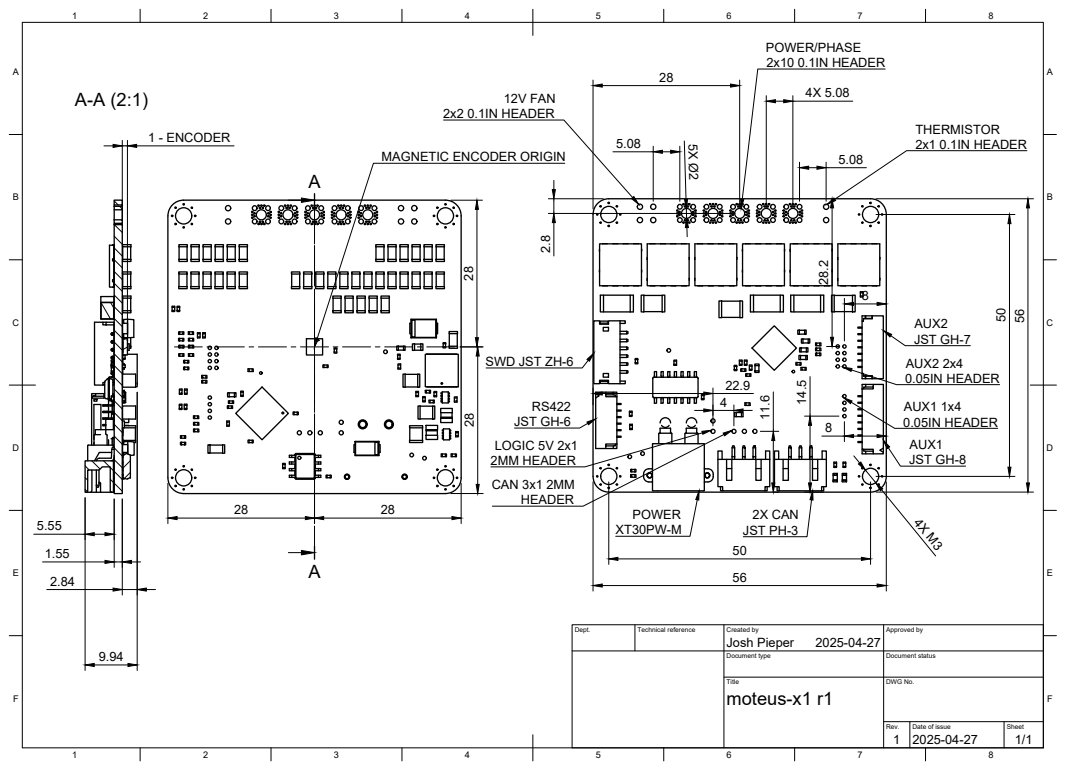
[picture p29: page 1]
Title; DWG No.; Rev.; Date of issue; Sheet; moteus-x1 r1; Josh Pieper; 2x10 0.1IN HEADER; JST GH-7; JST GH-8; AUX2 2x4 0.05IN HEADER; AUX1 1x4 0.05IN HEADER; JST GH-6; 2X CAN JST PH-3; CAN 3x1 2MM; LOGIC 5V 2x1 2MM HEADER; 1 - ENCODER; 12V FAN 2x2 0.1IN HEADER; 2x1 0.1IN HEADER

MAGNETIC ENCODER ORIGIN

SWD JST ZH-6

Dept. | Technical reference | Created by 2025-04-27 | Approved by

Document type | Document status

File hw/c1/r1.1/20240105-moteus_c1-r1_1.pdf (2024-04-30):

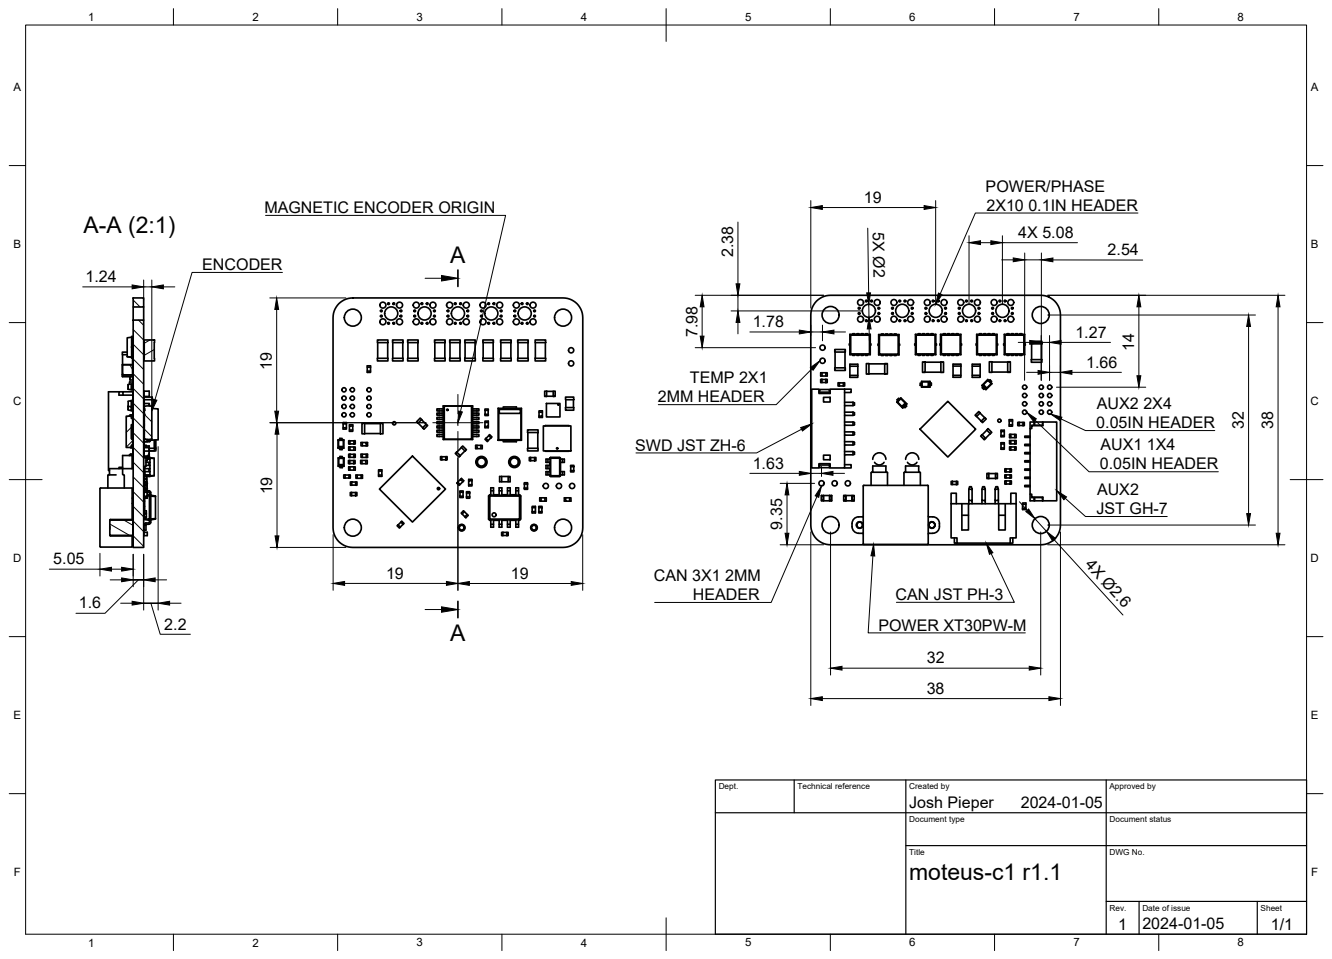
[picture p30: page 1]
Title; DWG No.; Rev.; Date of issue; Sheet; moteus-c1 r1.1; Josh Pieper; POWER XT30PW-M; 2X10 0.1IN HEADER; TEMP 2X1 2MM HEADER; CAN 3X1 2MM; JST GH-7; AUX2 2X4 0.05IN HEADER AUX1 1X4 0.05IN HEADER

MAGNETIC ENCODER ORIGIN

SWD JST ZH-6

CAN JST PH-3

Dept. | Technical reference | Created by 2024-01-05 | Approved by

Document type | Document status

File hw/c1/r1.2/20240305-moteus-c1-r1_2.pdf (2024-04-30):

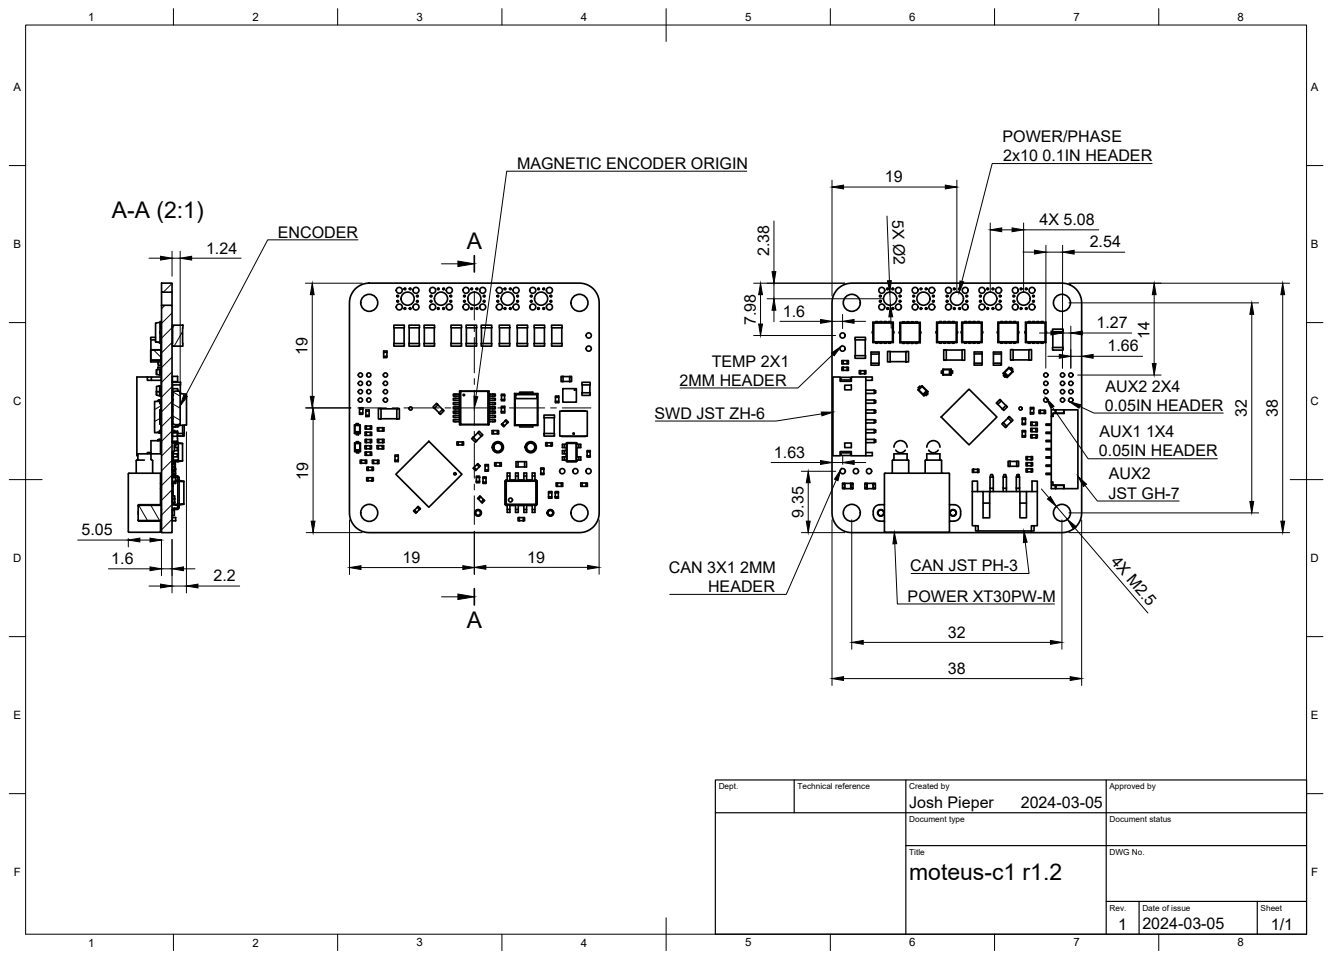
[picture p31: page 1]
Title; DWG No.; Rev.; Date of issue; Sheet; moteus-c1 r1.2; TEMP 2X1 2MM HEADER; CAN 3X1 2MM; HEADER; POWER XT30PW-M; JST GH-7; AUX1 1X4 0.05IN HEADER; AUX2 2X4 0.05IN HEADER

2x10 0.1IN HEADER MAGNETIC ENCODER ORIGIN 19 19

SWD JST ZH-6

CAN JST PH-3

Dept. | Technical reference | Created by Josh Pieper 2024-03-05 | Approved by

Document type | Document status

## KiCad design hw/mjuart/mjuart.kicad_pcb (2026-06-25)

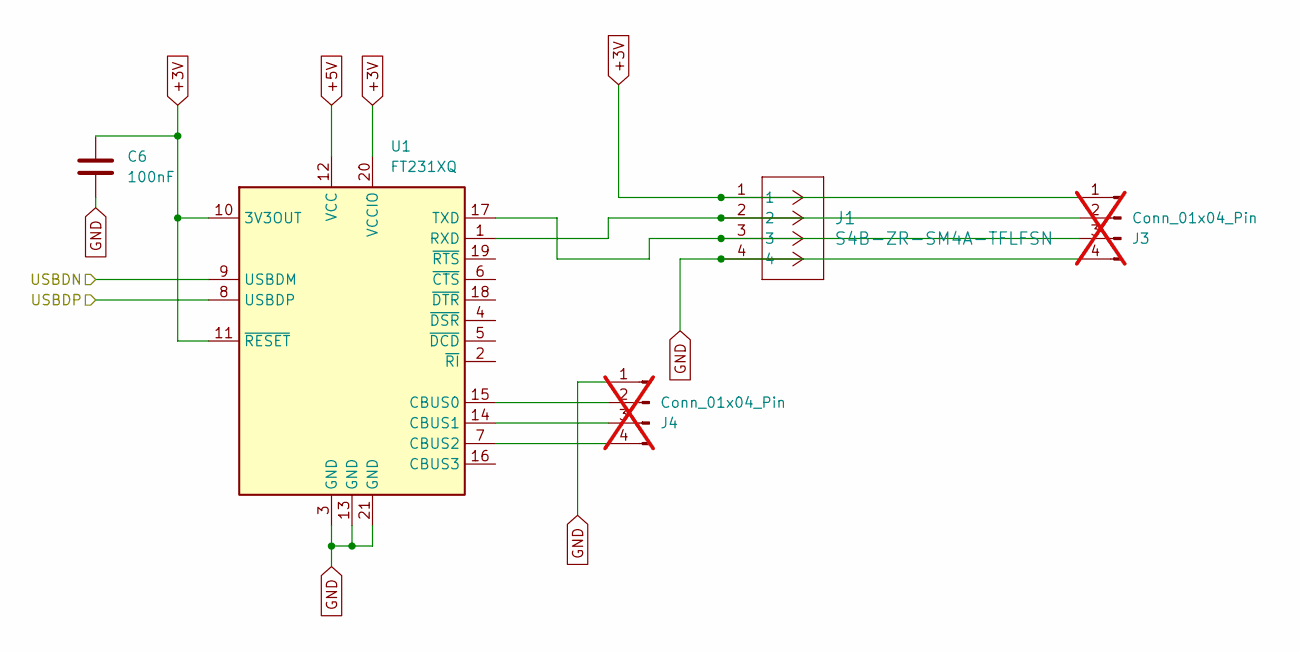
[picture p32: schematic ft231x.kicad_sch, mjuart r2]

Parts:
C6: 100nF; C_0603_1608Metric; MPN MF-CAP-0603-0.1uF
J1: S4B-ZR-SM4A-TFLFSN; CONN_S4B-ZR-SM4A-TF_JST; MPN S4B-ZR-SM4A-TF(LF)(SN)
J3, J4: Conn_01x04_Pin; testpad4; not fitted
U1: FT231XQ; QFN-20-1EP_4x4mm_P0.5mm_EP2.5x2.5mm; MPN FT231XQ-T

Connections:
+3V: C6.1, J1.1, J3.1, U1.10 (3V3OUT), U1.11 (~RESET), U1.20 (VCCIO)
+5V: U1.12 (VCC); also elsewhere on the board
/Power Input/USBDN: U1.9 (USBDM); also elsewhere on the board
/Power Input/USBDP: U1.8 (USBDP); also elsewhere on the board
GND: C6.2, J1.4, J3.4, J4.1, U1.3 (GND), U1.13 (GND), U1.21 (GND); also elsewhere on the board
unnamed: J1.2, J3.2, U1.1 (RXD)
unnamed: J1.3, J3.3, U1.17 (TXD)
unnamed: J4.2, U1.15 (CBUS0)
unnamed: J4.3, U1.14 (CBUS1)
unnamed: J4.4, U1.7 (CBUS2)

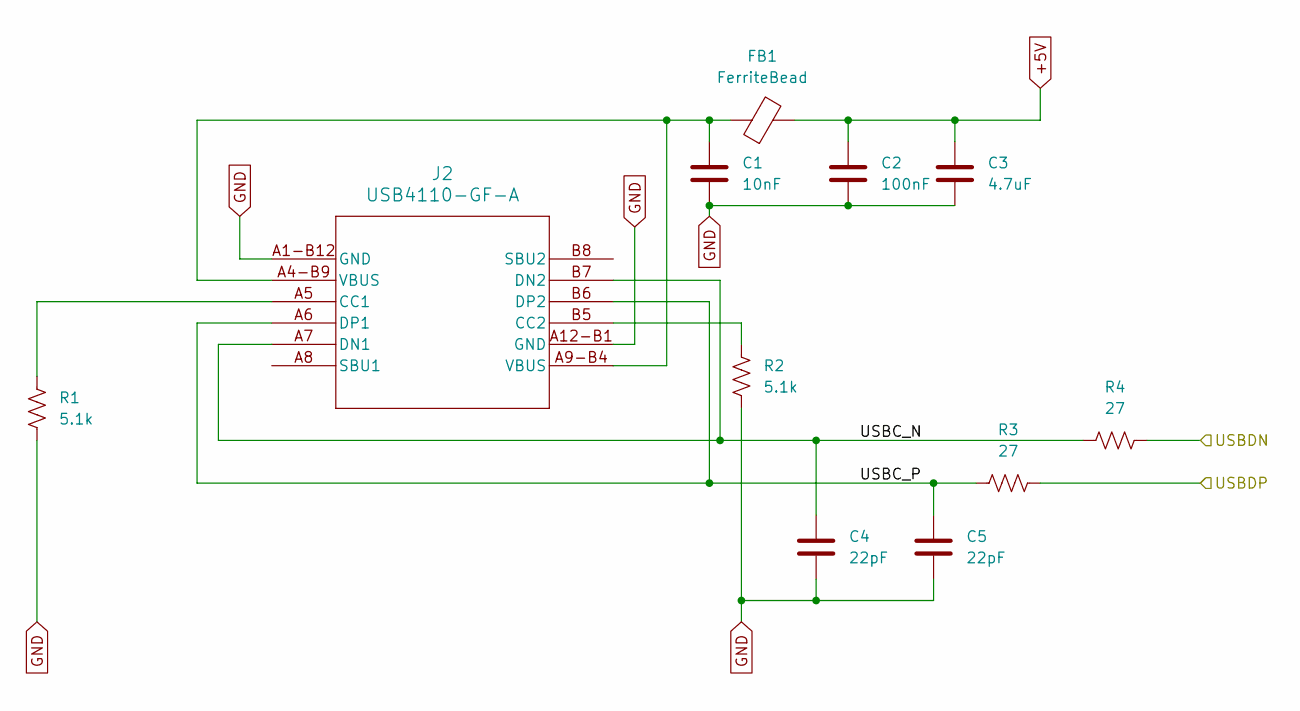
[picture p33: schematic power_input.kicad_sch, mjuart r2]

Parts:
C1: 10nF; C_0603_1608Metric; MPN MF-CAP-0603-0.01uF
C2: 100nF; C_0603_1608Metric; MPN MF-CAP-0603-0.1uF
C3: 4.7uF; C_0603_1608Metric; MPN GRT188C81E475KE13D
C4, C5: 22pF; C_0603_1608Metric; MPN MF-CAP-0603-22pF
FB1: FerriteBead; FB_MI0805K400R-10; MPN MI0805K400R-10
J2: USB4110-GF-A; USB4110-GF-A_GCT; MPN USB4110-GF-A
R1, R2: 5.1k; R_0603_1608Metric; MPN RC0603FR-075K1L
R3, R4: 27; R_0603_1608Metric; MPN MF-RES-0603-27

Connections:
+5V: C2.1, C3.1, FB1.2; also elsewhere on the board
/Power Input/USBC_N: C4.1, J2.A7 (DN1), J2.B7 (DN2), R4.1
/Power Input/USBC_P: C5.1, J2.A6 (DP1), J2.B6 (DP2), R3.1
/Power Input/USBDN: R4.2; also elsewhere on the board
/Power Input/USBDP: R3.2; also elsewhere on the board
GND: C1.2, C2.2, C3.2, C4.2, C5.2, J2.A1-B12 (GND), J2.A12-B1 (GND), R1.2, R2.2; also elsewhere on the board
unnamed: C1.1, FB1.1, J2.A4-B9 (VBUS), J2.A9-B4 (VBUS)
unnamed: J2.A5 (CC1), R1.1
unnamed: J2.B5 (CC2), R2.1

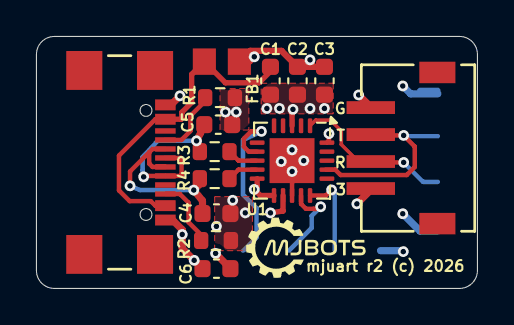
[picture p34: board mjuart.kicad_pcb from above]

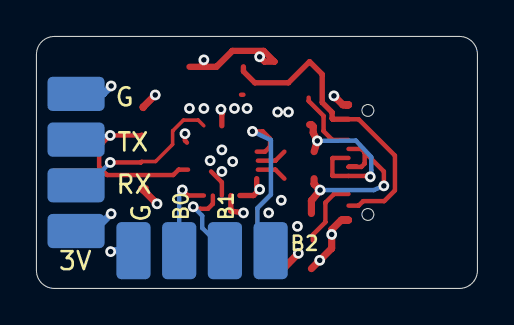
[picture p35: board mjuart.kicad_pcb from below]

Board: 4 copper layers, 24.5 x 14.0 mm, 16 parts (2 on the bottom side), 15 nets.

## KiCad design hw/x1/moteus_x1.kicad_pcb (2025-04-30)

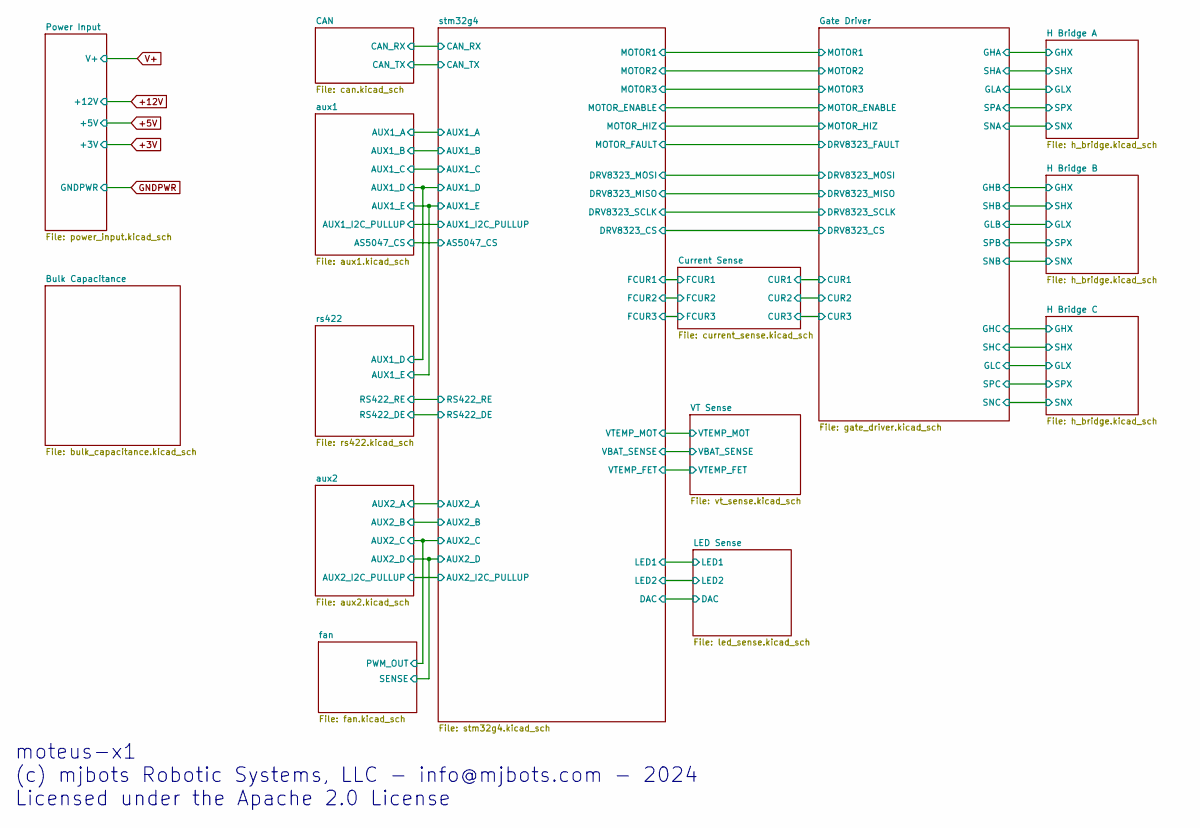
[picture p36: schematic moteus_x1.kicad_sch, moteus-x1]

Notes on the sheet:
moteus-x1 (c) mjbots Robotic Systems, LLC - info@mjbots.com - 2024 Licensed under the Apache 2.0 License

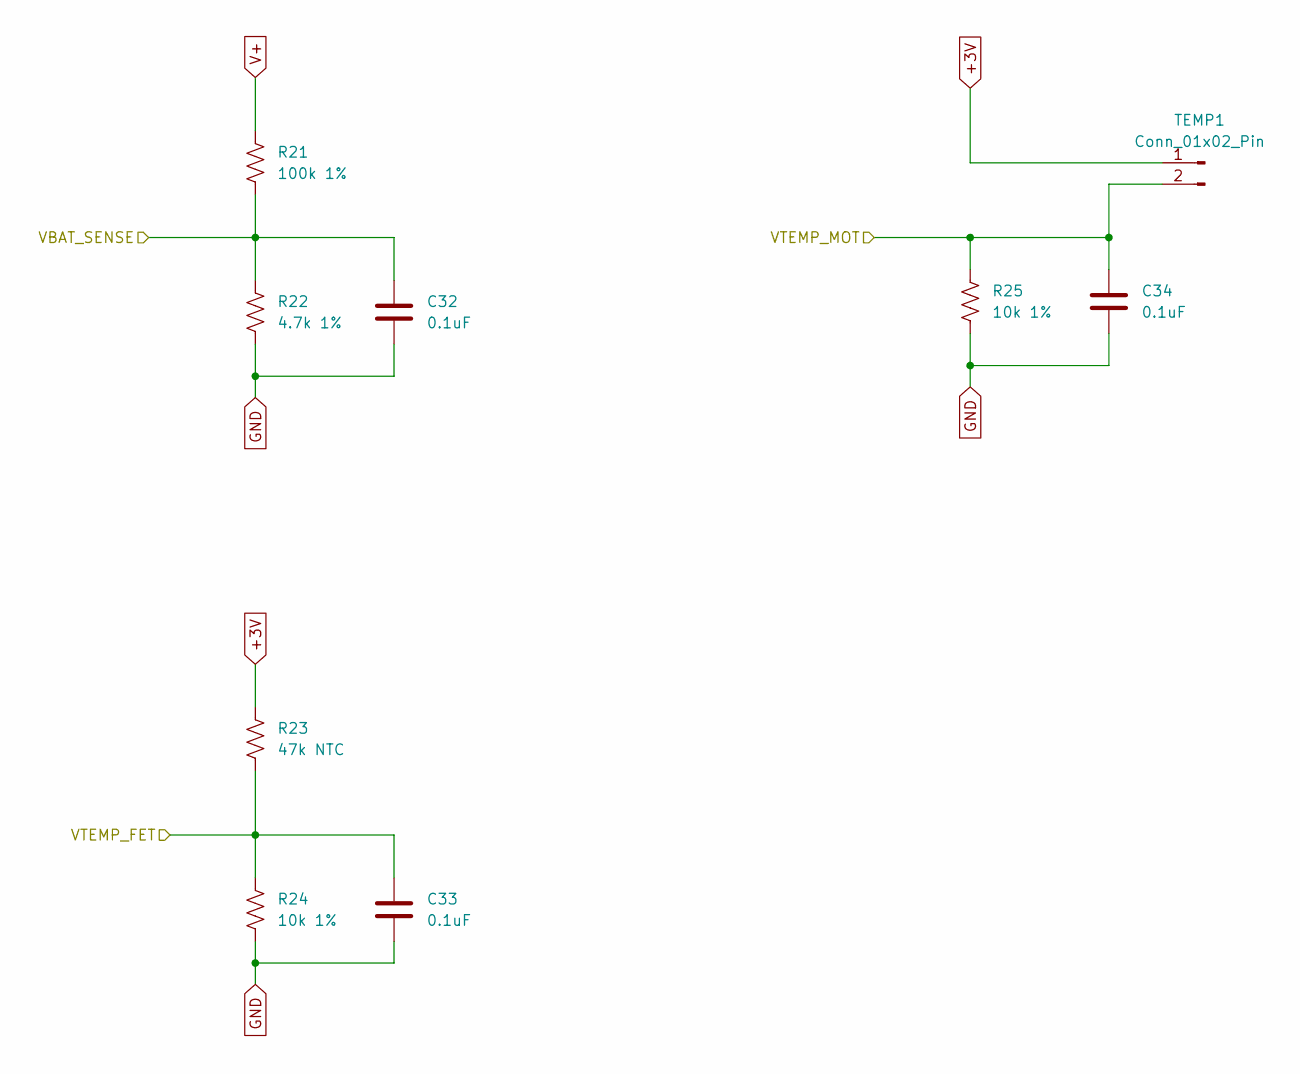
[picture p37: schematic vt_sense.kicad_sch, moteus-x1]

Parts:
C32, C33, C34: 0.1uF; C_0402_1005Metric; MPN MF-CAP-0402-0.1uF
R21: 100k 1%; R_0402_1005Metric; MPN RC0402FR-07100KL
R22: 4.7k 1%; R_0402_1005Metric; MPN RC0402FR-074K7L
R23: 47k NTC; R_0402_1005Metric; MPN NCP15WB473F03RC
R24, R25: 10k 1%; R_0402_1005Metric; MPN RC0402FR-0710KL
TEMP1: Conn_01x02_Pin; PinHeader_1x02_P2.54mm_Vertical

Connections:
+3V: R23.1, TEMP1.1; also elsewhere on the board
/VT Sense/VBAT_SENSE: C32.1, R21.2, R22.1; also elsewhere on the board
/VT Sense/VTEMP_FET: C33.1, R23.2, R24.1; also elsewhere on the board
/VT Sense/VTEMP_MOT: C34.1, R25.1, TEMP1.2; also elsewhere on the board
GND: C32.2, C33.2, C34.2, R22.2, R24.2, R25.2; also elsewhere on the board
V+: R21.1; also elsewhere on the board

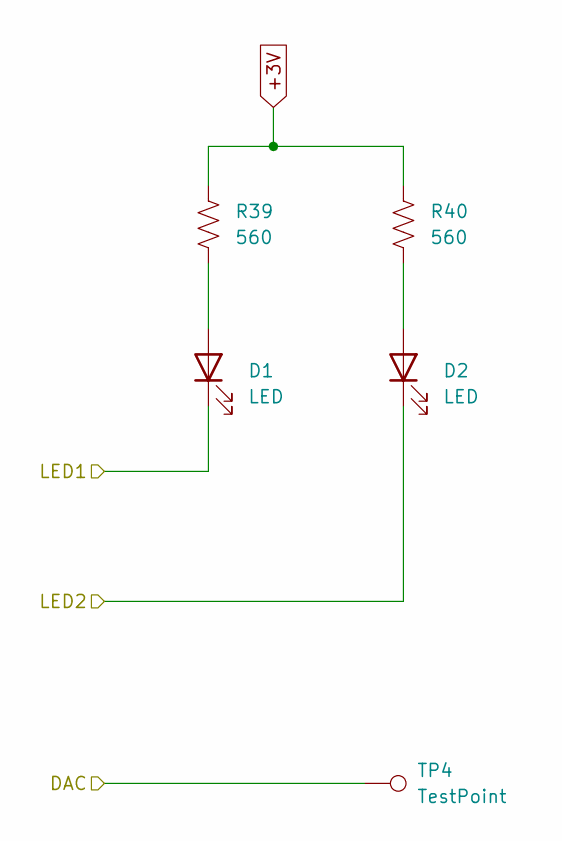
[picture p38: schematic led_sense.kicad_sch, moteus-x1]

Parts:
D1: LED; LED_0603_1608Metric; MPN MF-LED-0603-RED
D2: LED; LED_0603_1608Metric; MPN MF-LED-0603-GREEN
R39, R40: 560; R_0402_1005Metric; MPN MF-RES-0402-560
TP4: TestPoint; TestPoint_THTPad_D1.0mm_Drill0.5mm

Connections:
+3V: R39.1, R40.1; also elsewhere on the board
/LED Sense/DAC: TP4.1; also elsewhere on the board
/LED Sense/LED1: D1.1 (K); also elsewhere on the board
/LED Sense/LED2: D2.1 (K); also elsewhere on the board
unnamed: D1.2 (A), R39.2
unnamed: D2.2 (A), R40.2

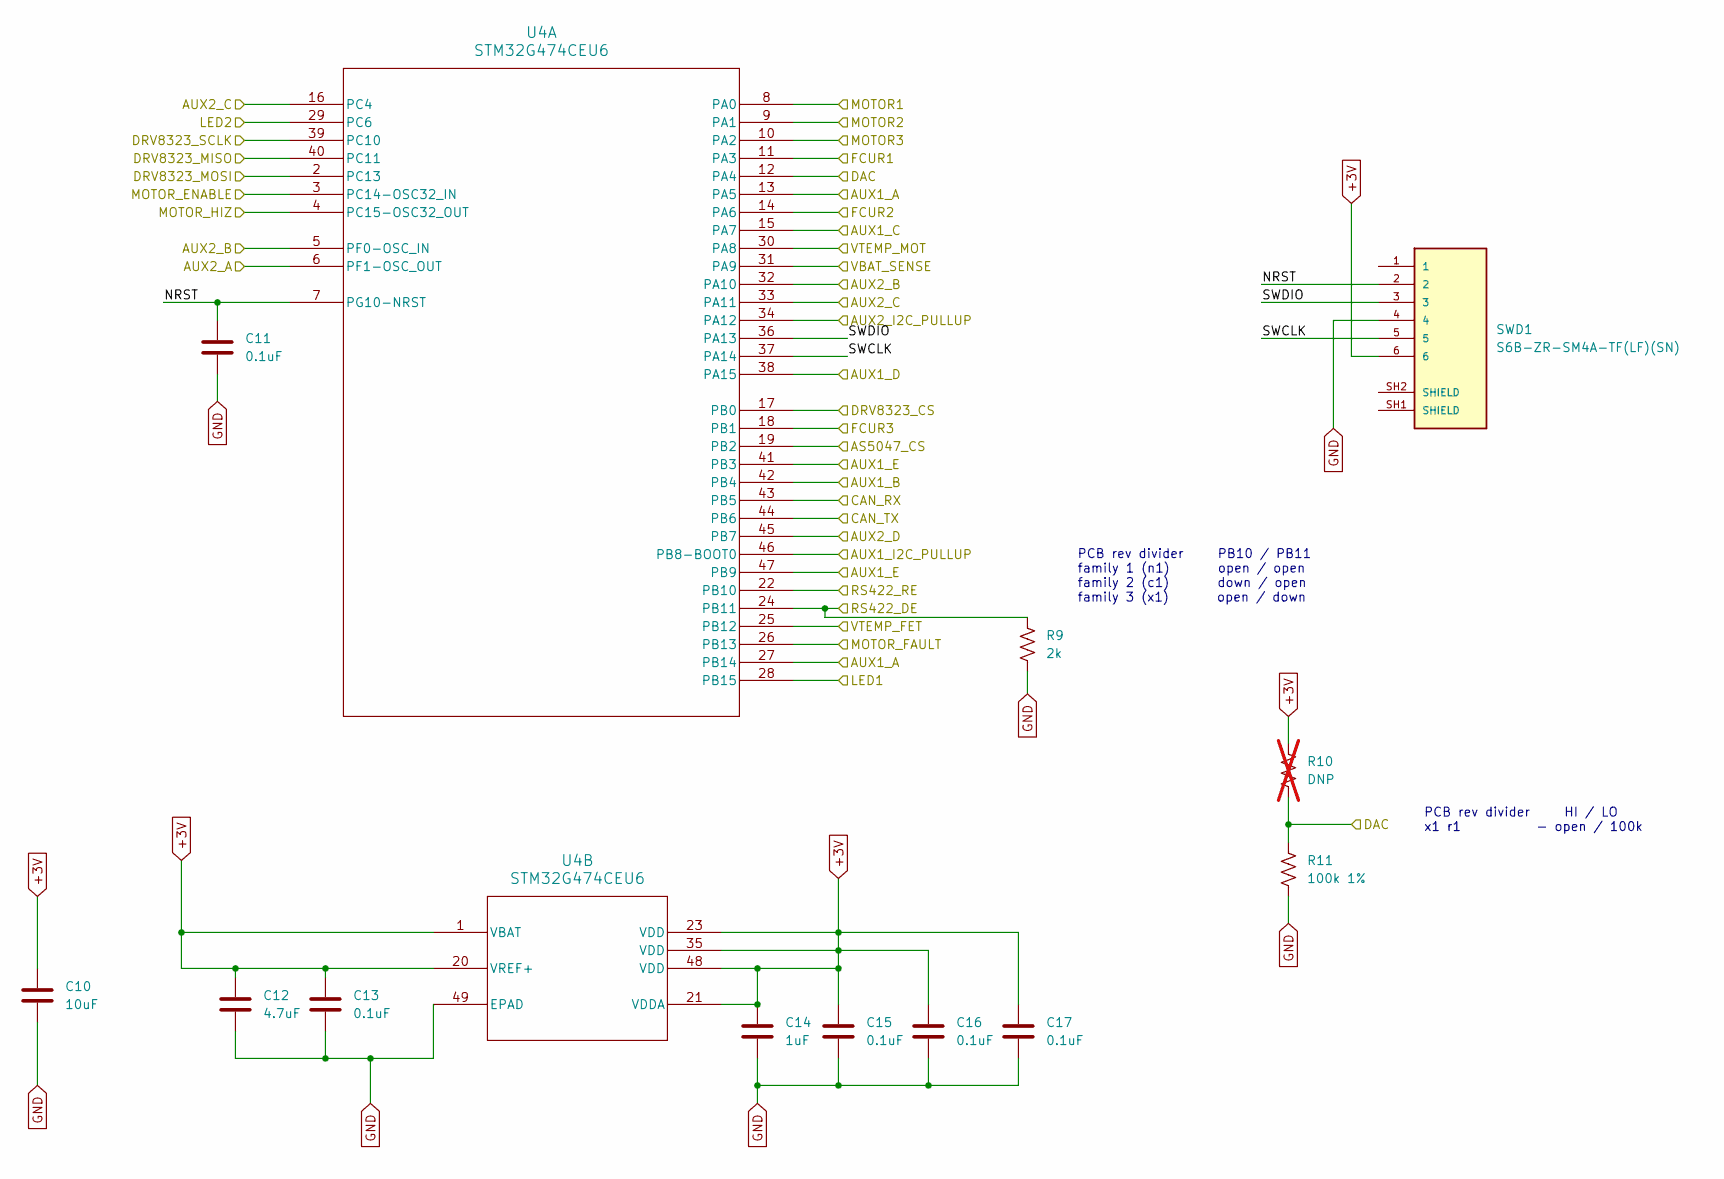
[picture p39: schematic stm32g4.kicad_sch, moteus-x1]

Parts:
C10: 10uF; C_1206_3216Metric; MPN MF-CAP-1206-10uF
C11, C13, C15, C16, C17: 0.1uF; C_0402_1005Metric; MPN MF-CAP-0402-0.1uF
C12: 4.7uF; C_0603_1608Metric; MPN CL10A475KP8NNNC
C14: 1uF; C_0402_1005Metric; MPN MF-CAP-0402-1uF
R9: 2k; R_0402_1005Metric; MPN MF-RES-0402-2K
R10: DNP; R_0402_1005Metric; not fitted
R11: 100k 1%; R_0402_1005Metric; MPN RC0402FR-07100KL
SWD1: S6B-ZR-SM4A-TF(LF)(SN); JST_S6B-ZR-SM4A-TF(LF)(SN); MPN S6B-ZR-SM4A-TF(LF)(SN)
U4: STM32G474CEU6; UFQFPN-48_7X7X0P55MM; MPN STM32G474CEU6

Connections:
+3V: C10.1, C12.1, C13.1, C14.1, C15.1, C16.1, C17.1, R10.1, SWD1.6, U4.1 (VBAT), U4.20 (VREF+), U4.21 (VDDA), U4.23 (VDD), U4.35 (VDD), U4.48 (VDD); also elsewhere on the board
/CAN/CAN_RX: U4.43 (PB5); also elsewhere on the board
/CAN/CAN_TX: U4.44 (PB6); also elsewhere on the board
/Current Sense/FCUR1: U4.11 (PA3); also elsewhere on the board
/Current Sense/FCUR2: U4.14 (PA6); also elsewhere on the board
/Current Sense/FCUR3: U4.18 (PB1); also elsewhere on the board
/Gate Driver/DRV8323_CS: U4.17 (PB0); also elsewhere on the board
/Gate Driver/DRV8323_FAULT: U4.26 (PB13); also elsewhere on the board
/Gate Driver/DRV8323_MISO: U4.40 (PC11); also elsewhere on the board
/Gate Driver/DRV8323_MOSI: U4.2 (PC13); also elsewhere on the board
/Gate Driver/DRV8323_SCLK: U4.39 (PC10); also elsewhere on the board
/Gate Driver/MOTOR1: U4.8 (PA0); also elsewhere on the board
/Gate Driver/MOTOR2: U4.9 (PA1); also elsewhere on the board
/Gate Driver/MOTOR3: U4.10 (PA2); also elsewhere on the board
/Gate Driver/MOTOR_ENABLE: U4.3 (PC14-OSC32_IN); also elsewhere on the board
/Gate Driver/MOTOR_HIZ: U4.4 (PC15-OSC32_OUT); also elsewhere on the board
/LED Sense/DAC: R10.2, R11.1, U4.12 (PA4); also elsewhere on the board
/LED Sense/LED1: U4.28 (PB15); also elsewhere on the board
/LED Sense/LED2: U4.29 (PC6); also elsewhere on the board
/VT Sense/VBAT_SENSE: U4.31 (PA9); also elsewhere on the board
/VT Sense/VTEMP_FET: U4.25 (PB12); also elsewhere on the board
/VT Sense/VTEMP_MOT: U4.30 (PA8); also elsewhere on the board
/aux1/AS5047_CS: U4.19 (PB2); also elsewhere on the board
/aux1/AUX1_A: U4.13 (PA5), U4.27 (PB14); also elsewhere on the board
/aux1/AUX1_B: U4.42 (PB4); also elsewhere on the board
/aux1/AUX1_C: U4.15 (PA7); also elsewhere on the board
/aux1/AUX1_D: U4.38 (PA15); also elsewhere on the board
/aux1/AUX1_E: U4.41 (PB3), U4.47 (PB9); also elsewhere on the board
/aux1/AUX1_I2C_PULLUP: U4.46 (PB8-BOOT0); also elsewhere on the board
/aux2/AUX2_A: U4.6 (PF1-OSC_OUT); also elsewhere on the board
/aux2/AUX2_B: U4.5 (PF0-OSC_IN), U4.32 (PA10); also elsewhere on the board
/aux2/AUX2_C: U4.16 (PC4), U4.33 (PA11); also elsewhere on the board
/aux2/AUX2_D: U4.45 (PB7); also elsewhere on the board
/aux2/AUX2_I2C_PULLUP: U4.34 (PA12); also elsewhere on the board
/rs422/RS422_DE: R9.1, U4.24 (PB11); also elsewhere on the board
/rs422/RS422_RE: U4.22 (PB10); also elsewhere on the board
/stm32g4/NRST: C11.1, SWD1.2, U4.7 (PG10-NRST)
/stm32g4/SWCLK: SWD1.5, U4.37 (PA14)
/stm32g4/SWDIO: SWD1.3, U4.36 (PA13)
GND: C10.2, C11.2, C12.2, C13.2, C14.2, C15.2, C16.2, C17.2, R9.2, R11.2, SWD1.4, U4.49 (EPAD); also elsewhere on the board

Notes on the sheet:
PCB rev divider HI / LO x1 r1 - open / 100k
PCB rev divider PB10 / PB11 family 1 (n1) open / open family 2 (c1) down / open family 3 (x1) open / down

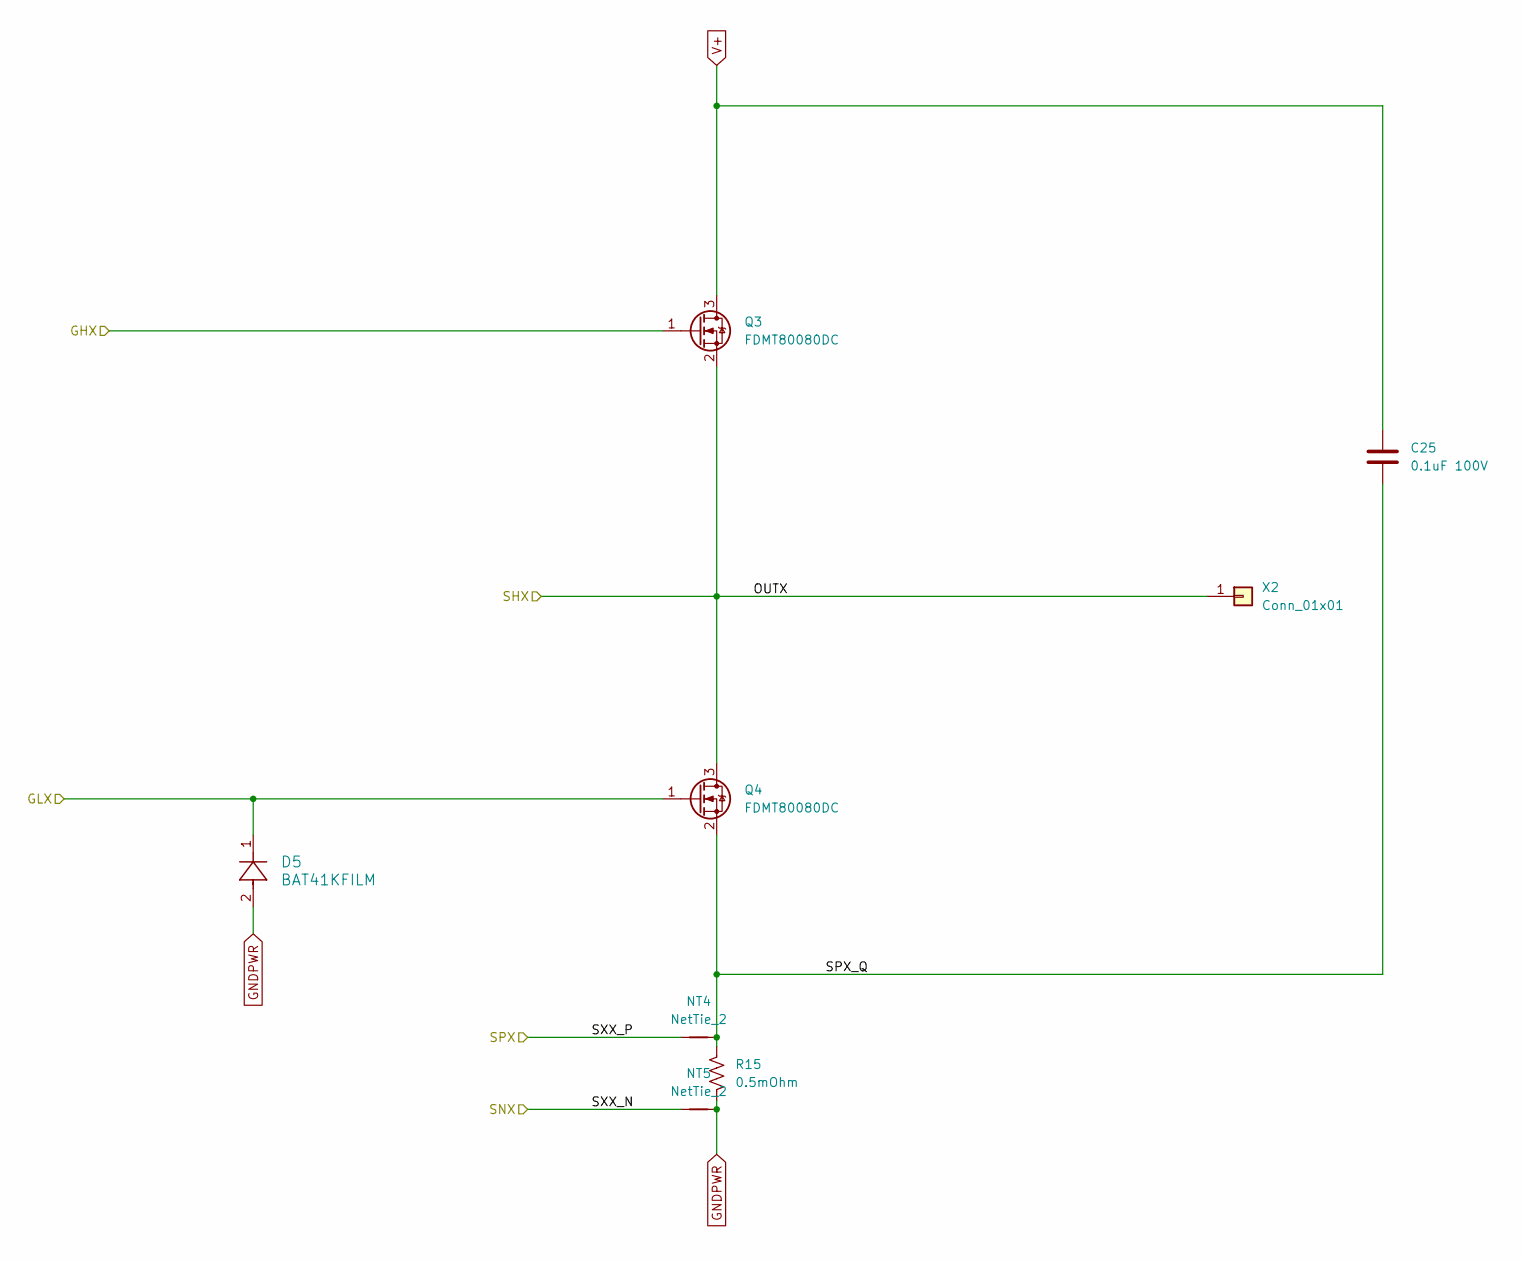
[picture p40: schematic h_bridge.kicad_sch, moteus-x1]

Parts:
C25: 0.1uF 100V; C_1812_4532Metric; MPN 18121C104MAT2A
D5: BAT41KFILM; SOD-523_STM; MPN BAT41KFILM
NT4, NT5: NetTie_2; NetTie-2_SMD_Pad0.2
Q3, Q4: FDMT80080DC; PQFN_8x8; MPN FDMT80080DC
R15: 0.5mOhm; R_2512_6332Metric; MPN WSLF2512L5000FEA
X2: Conn_01x01; POWER_M2.5

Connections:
/Gate Driver/GHB: Q3.1 (G); also elsewhere on the board
/Gate Driver/GLB: D5.1, Q4.1 (G); also elsewhere on the board
/H Bridge B/OUTX: Q3.2 (S), Q4.3 (D), X2.1; also elsewhere on the board
/H Bridge B/SPX_Q: C25.2, NT4.2, Q4.2 (S), R15.1
/H Bridge B/SXX_N: NT5.1; also elsewhere on the board
/H Bridge B/SXX_P: NT4.1; also elsewhere on the board
GNDPWR: D5.2, NT5.2, R15.2; also elsewhere on the board
V+: C25.1, Q3.3 (D); also elsewhere on the board

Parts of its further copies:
C24, C26: 0.1uF 100V; C_1812_4532Metric; MPN 18121C104MAT2A
D4, D6: BAT41KFILM; SOD-523_STM; MPN BAT41KFILM
NT2, NT3, NT6, NT7: NetTie_2; NetTie-2_SMD_Pad0.2
Q1, Q2, Q5, Q6: FDMT80080DC; PQFN_8x8; MPN FDMT80080DC
R14, R16: 0.5mOhm; R_2512_6332Metric; MPN WSLF2512L5000FEA
X1, X3: Conn_01x01; POWER_M2.5

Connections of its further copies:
/Gate Driver/GHA: Q1.1 (G); also elsewhere on the board
/Gate Driver/GHC: Q5.1 (G); also elsewhere on the board
/Gate Driver/GLA: D4.1, Q2.1 (G); also elsewhere on the board
/Gate Driver/GLC: D6.1, Q6.1 (G); also elsewhere on the board
/H Bridge A/OUTX: Q1.2 (S), Q2.3 (D), X1.1; also elsewhere on the board
/H Bridge A/SPX_Q: C24.2, NT2.2, Q2.2 (S), R14.1
/H Bridge A/SXX_N: NT3.1; also elsewhere on the board
/H Bridge A/SXX_P: NT2.1; also elsewhere on the board
/H Bridge C/OUTX: Q5.2 (S), Q6.3 (D), X3.1; also elsewhere on the board
/H Bridge C/SPX_Q: C26.2, NT6.2, Q6.2 (S), R16.1
/H Bridge C/SXX_N: NT7.1; also elsewhere on the board
/H Bridge C/SXX_P: NT6.1; also elsewhere on the board
GNDPWR: D4.2, D6.2, NT3.2, NT7.2, R14.2, R16.2; also elsewhere on the board
V+: C24.1, C26.1, Q1.3 (D), Q5.3 (D); also elsewhere on the board

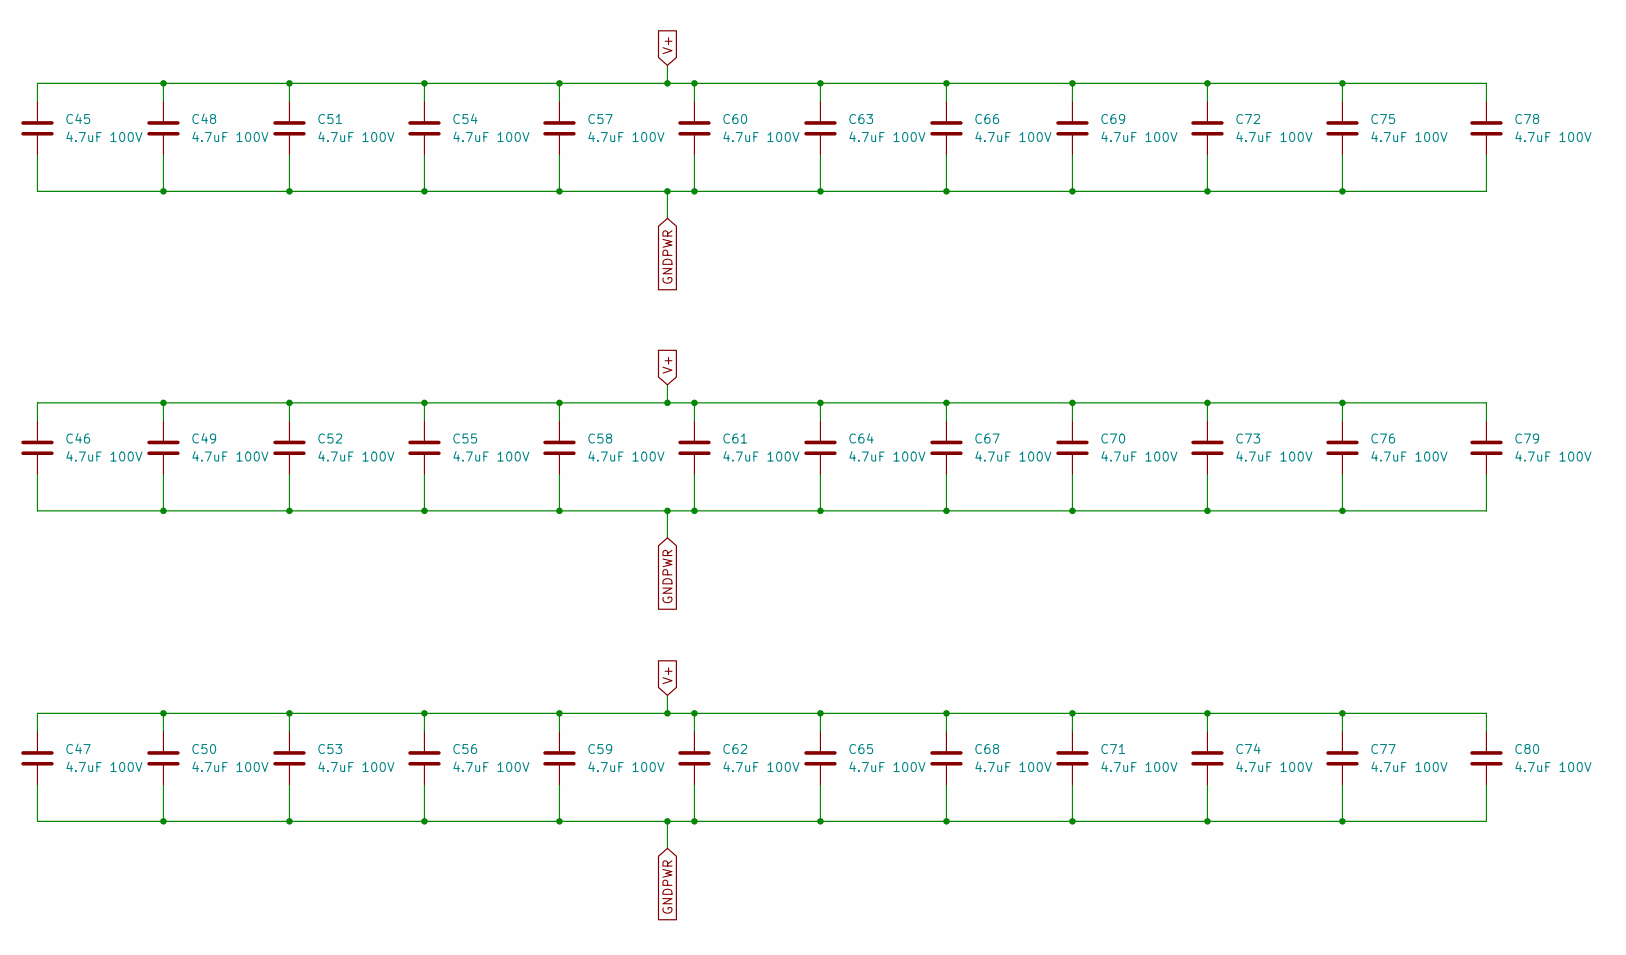
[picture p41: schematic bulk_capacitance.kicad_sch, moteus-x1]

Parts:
C45, C46, C47, C48, C49, C50, C51, C52, C53, C54, C55, C56, C57, C58, C59, C60, C61, C62, C63, C64, C65, C66, C67, C68, C69, C70, C71, C72, C73, C74, C75, C76, C77, C78, C79, C80: 4.7uF 100V; C_1206_3216Metric; MPN GRJ31CC72A475KE01K

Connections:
GNDPWR: C45.2, C46.2, C47.2, C48.2, C49.2, C50.2, C51.2, C52.2, C53.2, C54.2, C55.2, C56.2, C57.2, C58.2, C59.2, C60.2, C61.2, C62.2, C63.2, C64.2, C65.2, C66.2, C67.2, C68.2, C69.2, C70.2, C71.2, C72.2, C73.2, C74.2, C75.2, C76.2, C77.2, C78.2, C79.2, C80.2; also elsewhere on the board
V+: C45.1, C46.1, C47.1, C48.1, C49.1, C50.1, C51.1, C52.1, C53.1, C54.1, C55.1, C56.1, C57.1, C58.1, C59.1, C60.1, C61.1, C62.1, C63.1, C64.1, C65.1, C66.1, C67.1, C68.1, C69.1, C70.1, C71.1, C72.1, C73.1, C74.1, C75.1, C76.1, C77.1, C78.1, C79.1, C80.1; also elsewhere on the board

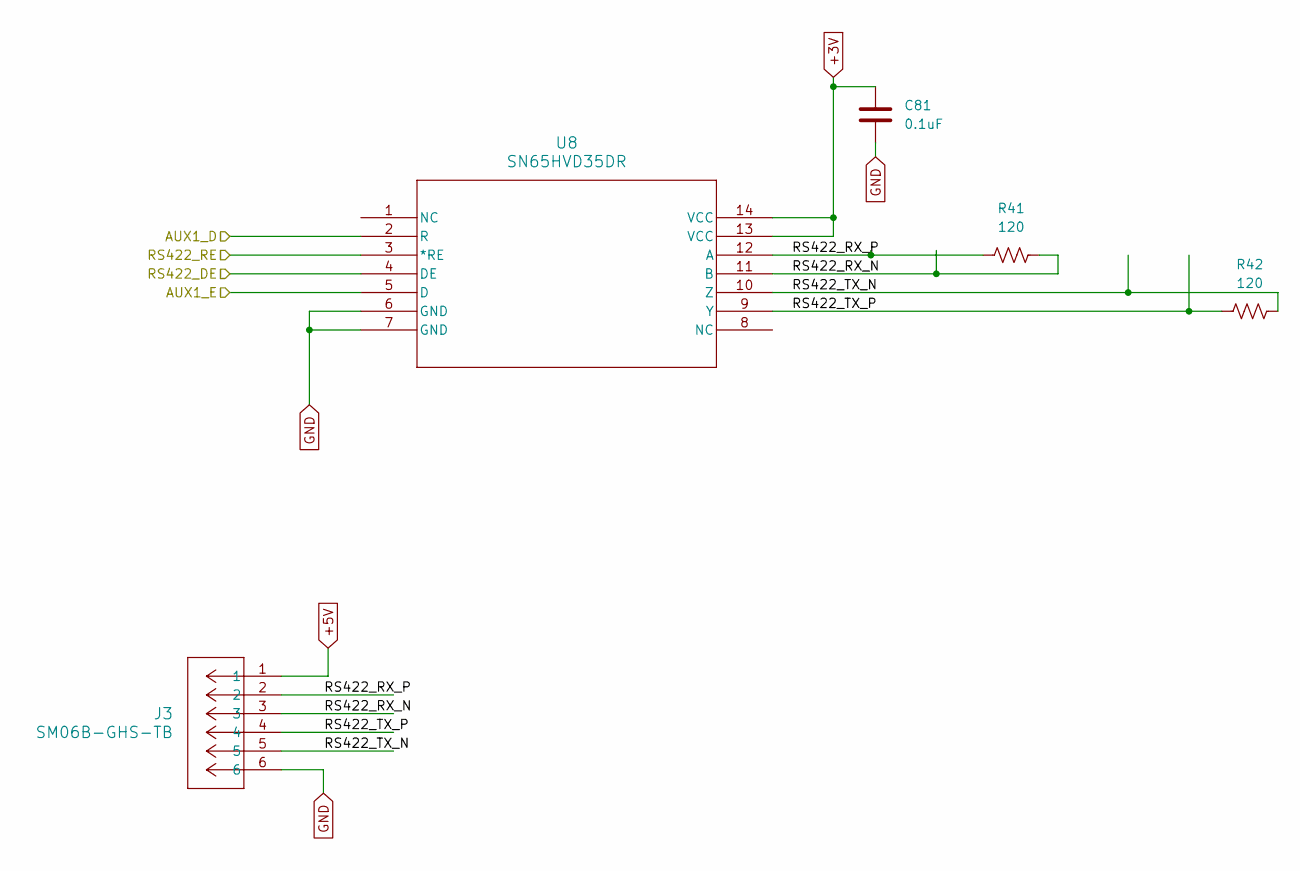
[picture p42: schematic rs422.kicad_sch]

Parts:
C81: 0.1uF; C_0402_1005Metric; MPN MF-CAP-0402-0.1uF
J3: SM06B-GHS-TB; CONN_SM06B-GHS-TB_JST; MPN SM06B-GHS-TB(LF)(SN)
R41, R42: 120; R_0402_1005Metric; MPN RC0402FR-07120RL
U8: SN65HVD35DR; D14; MPN SN65HVD35DR

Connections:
+3V: C81.1, U8.13 (VCC), U8.14 (VCC); also elsewhere on the board
+5V: J3.1; also elsewhere on the board
/aux1/AUX1_D: U8.2 (R); also elsewhere on the board
/aux1/AUX1_E: U8.5 (D); also elsewhere on the board
/rs422/RS422_DE: U8.4 (DE); also elsewhere on the board
/rs422/RS422_RE: U8.3 (*RE); also elsewhere on the board
/rs422/RS422_RX_N: J3.3, R41.2, U8.11 (B)
/rs422/RS422_RX_P: J3.2, R41.1, U8.12 (A)
/rs422/RS422_TX_N: J3.5, R42.2, U8.10 (Z)
/rs422/RS422_TX_P: J3.4, R42.1, U8.9 (Y)
GND: C81.2, J3.6, U8.6 (GND), U8.7 (GND); also elsewhere on the board

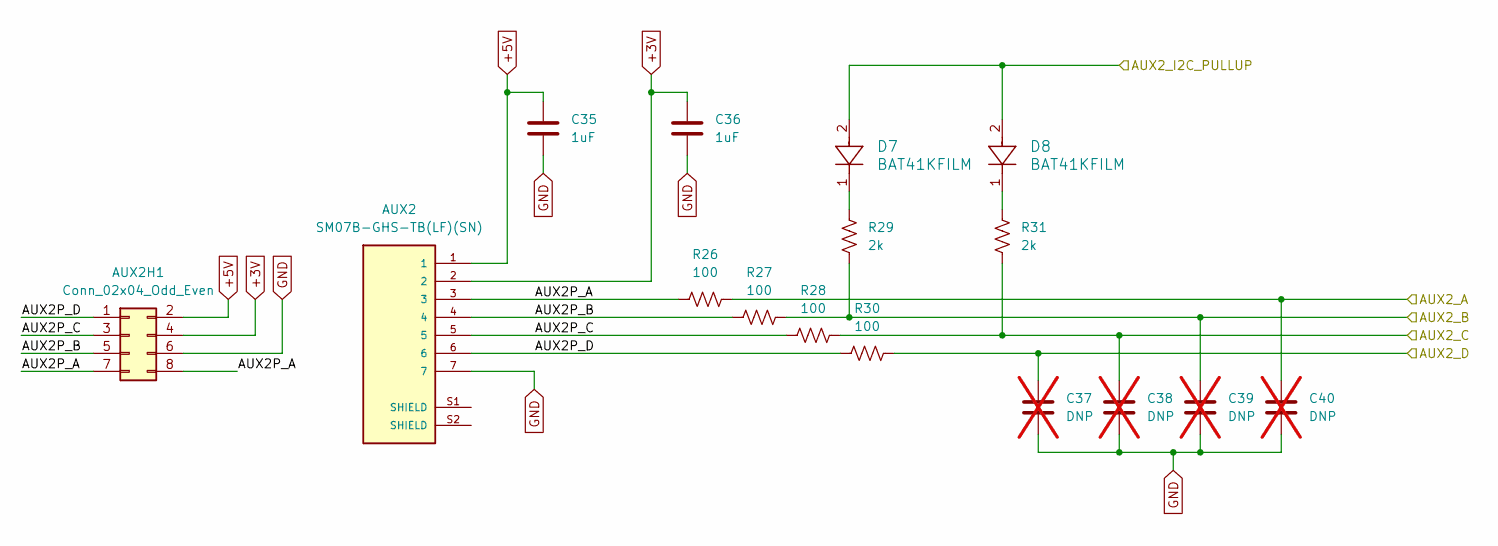
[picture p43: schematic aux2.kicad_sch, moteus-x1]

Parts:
AUX2: SM07B-GHS-TB(LF)(SN); JST_SM07B-GHS-TB(LF)(SN); MPN SM07B-GHS-TB(LF)(SN)
AUX2H1: Conn_02x04_Odd_Even; PinHeader_2x04_P1.27mm_Vertical
C35, C36: 1uF; C_0402_1005Metric; MPN MF-CAP-0402-1uF
C37, C38, C39, C40: DNP; C_0402_1005Metric; not fitted
D7, D8: BAT41KFILM; SOD-523_STM; MPN BAT41KFILM
R26, R27, R28, R30: 100; R_0402_1005Metric; MPN MF-RES-0402-100
R29, R31: 2k; R_0402_1005Metric; MPN MF-RES-0402-2K

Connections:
+3V: AUX2.2, AUX2H1.4, C36.1; also elsewhere on the board
+5V: AUX2.1, AUX2H1.2, C35.1; also elsewhere on the board
/aux2/AUX2P_A: AUX2.3, AUX2H1.7, AUX2H1.8, R26.1
/aux2/AUX2P_B: AUX2.4, AUX2H1.5, R27.1
/aux2/AUX2P_C: AUX2.5, AUX2H1.3, R28.1
/aux2/AUX2P_D: AUX2.6, AUX2H1.1, R30.1
/aux2/AUX2_A: C40.1, R26.2; also elsewhere on the board
/aux2/AUX2_B: C39.1, R27.2, R29.2; also elsewhere on the board
/aux2/AUX2_C: C38.1, R28.2, R31.2; also elsewhere on the board
/aux2/AUX2_D: C37.1, R30.2; also elsewhere on the board
/aux2/AUX2_I2C_PULLUP: D7.2, D8.2; also elsewhere on the board
GND: AUX2.7, AUX2H1.6, C35.2, C36.2, C37.2, C38.2, C39.2, C40.2; also elsewhere on the board
unnamed: D7.1, R29.1
unnamed: D8.1, R31.1

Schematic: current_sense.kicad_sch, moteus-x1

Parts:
C27, C28, C29: 1000pF; C_0402_1005Metric; MPN MF-CAP-0402-1nF
R17, R18, R19: 22; R_0402_1005Metric; MPN MF-RES-0402-22

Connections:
/Current Sense/CUR1: R17.1; also elsewhere on the board
/Current Sense/CUR2: R18.1; also elsewhere on the board
/Current Sense/CUR3: R19.1; also elsewhere on the board
/Current Sense/FCUR1: C27.1, R17.2; also elsewhere on the board
/Current Sense/FCUR2: C28.1, R18.2; also elsewhere on the board
/Current Sense/FCUR3: C29.1, R19.2; also elsewhere on the board
GND: C27.2, C28.2, C29.2; also elsewhere on the board

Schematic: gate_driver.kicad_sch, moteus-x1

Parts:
C18: 1uF; C_0603_1608Metric; MPN MF-CAP-0603-1uF
C19: 0.1uF 100V; C_0603_1608Metric; MPN GCJ188R72A104KA01D
C20: 1uF; C_0402_1005Metric; MPN MF-CAP-0402-1uF
C21: 1uF 25V; C_0603_1608Metric; MPN C1608X7R1E105K080AE
C22: 47nF 100V; C_0603_1608Metric; MPN C0603X473K1RAC7867
C23: 1uF; C_0603_1608Metric; MPN C1608X7R1E105K080AE
R12, R13: 2k; R_0402_1005Metric; MPN MF-RES-0402-2K
U5: DRV8353SRTAR; RTA0040B; MPN DRV8353SRTAR

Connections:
+3V: C18.2, R12.1, R13.1, U5.24 (VREF); also elsewhere on the board
+12V: C19.2, U5.3 (VM); also elsewhere on the board
/Current Sense/CUR1: U5.21 (SOC); also elsewhere on the board
/Current Sense/CUR2: U5.22 (SOB); also elsewhere on the board
/Current Sense/CUR3: U5.23 (SOA); also elsewhere on the board
/Gate Driver/CPH: C22.2, U5.2 (CPH)
/Gate Driver/CPL: C22.1, U5.1 (CPL)
/Gate Driver/DRV8323_CS: U5.30 (SCS_N); also elsewhere on the board
/Gate Driver/DRV8323_FAULT: R13.2, U5.26 (FAULT_N); also elsewhere on the board
/Gate Driver/DRV8323_MISO: R12.2, U5.27 (SDO); also elsewhere on the board
/Gate Driver/DRV8323_MOSI: U5.28 (SDI); also elsewhere on the board
/Gate Driver/DRV8323_SCLK: U5.29 (SCLK); also elsewhere on the board
/Gate Driver/GHA: U5.6 (GHA); also elsewhere on the board
/Gate Driver/GHB: U5.15 (GHB); also elsewhere on the board
/Gate Driver/GHC: U5.16 (GHC); also elsewhere on the board
/Gate Driver/GLA: U5.8 (GLA); also elsewhere on the board
/Gate Driver/GLB: U5.13 (GLB); also elsewhere on the board
/Gate Driver/GLC: U5.18 (GLC); also elsewhere on the board
/Gate Driver/MOTOR1: U5.32 (INHA); also elsewhere on the board
/Gate Driver/MOTOR2: U5.34 (INHB); also elsewhere on the board
/Gate Driver/MOTOR3: U5.36 (INHC); also elsewhere on the board
/Gate Driver/MOTOR_ENABLE: U5.31 (ENABLE); also elsewhere on the board
/Gate Driver/MOTOR_HIZ: U5.33 (INLA), U5.35 (INLB), U5.37 (INLC); also elsewhere on the board
/H Bridge A/OUTX: U5.7 (SHA); also elsewhere on the board
/H Bridge A/SXX_N: U5.10 (SNA); also elsewhere on the board
/H Bridge A/SXX_P: U5.9 (SPA); also elsewhere on the board
/H Bridge B/OUTX: U5.14 (SHB); also elsewhere on the board
/H Bridge B/SXX_N: U5.11 (SNB); also elsewhere on the board
/H Bridge B/SXX_P: U5.12 (SPB); also elsewhere on the board
/H Bridge C/OUTX: U5.17 (SHC); also elsewhere on the board
/H Bridge C/SXX_N: U5.20 (SNC); also elsewhere on the board
/H Bridge C/SXX_P: U5.19 (SPC); also elsewhere on the board
GND: C18.1, C20.1, C23.1, U5.25 (AGND); also elsewhere on the board
GNDPWR: C19.1, U5.39 (PGND), U5.41 (PAD); also elsewhere on the board
unnamed: C20.2, U5.38 (DVDD)
unnamed: C21.2, U5.5 (VCP)
unnamed: C23.2, U5.40 (VGLS)
V+: C21.1, U5.4 (VDRAIN); also elsewhere on the board

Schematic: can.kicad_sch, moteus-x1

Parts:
C30, C31: 0.1uF; C_0402_1005Metric; MPN MF-CAP-0402-0.1uF
CAN1, CAN2: S3B-PH-SM4-TB(LF)(SN); JST_S3B-PH-SM4-TB(LF)(SN); MPN S3B-PH-SM4-TB(LF)(SN)
CAN_DBG1: Conn_01x03_Pin; PinHeader_1x03_P2.00mm_Vertical
R20: 120; R_0603_1608Metric; not fitted
U6: TCAN1057AEV-Q1; SOIC-8_3.9x4.9mm_P1.27mm; MPN TCAN1057AEVDRQ1

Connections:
+3V: C30.1, U6.5 (VIO); also elsewhere on the board
+5V: C31.1, U6.3 (VCC); also elsewhere on the board
/CAN/CAN_N: CAN1.2, CAN2.2, CAN_DBG1.2, R20.2, U6.6 (CANL)
/CAN/CAN_P: CAN1.1, CAN2.1, CAN_DBG1.1, R20.1, U6.7 (CANH)
/CAN/CAN_RX: U6.4 (RXD); also elsewhere on the board
/CAN/CAN_TX: U6.1 (TXD); also elsewhere on the board
GND: C30.2, C31.2, CAN1.3, CAN2.3, CAN_DBG1.3, U6.2 (GND), U6.8 (STB), U6.9 (PAD); also elsewhere on the board

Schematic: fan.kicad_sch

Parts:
C82: 4.7uF; C_1206_3216Metric; MPN GRJ31CC72A475KE01K
FAN1: Conn_01x04_Pin; PinSocket_2x02_P2.54mm_Vertical
R43, R44: 100; R_0402_1005Metric; MPN MF-RES-0402-100

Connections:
+12V: C82.1, FAN1.2; also elsewhere on the board
/aux2/AUX2_C: R43.1; also elsewhere on the board
/aux2/AUX2_D: R44.1; also elsewhere on the board
GND: C82.2, FAN1.1; also elsewhere on the board
unnamed: FAN1.3, R44.2
unnamed: FAN1.4, R43.2

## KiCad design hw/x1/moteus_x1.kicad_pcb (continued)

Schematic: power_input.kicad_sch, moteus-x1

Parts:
C1: 1uF 100V; C_0805_2012Metric; MPN GCM21BC72A105KE36L
C2: 0.1uF 100V; C_0603_1608Metric; MPN GCJ188R72A104KA01D
C3, C6: 1uF; C_0402_1005Metric; MPN MF-CAP-0402-1uF
C4, C7, C9: 22uF; C_1210_3225Metric; MPN GRM32ER71E226KE15L
C5: 5600pF; C_0402_1005Metric; MPN GCM155R71E562KA37D
C8: DNP; C_0402_1005Metric; not fitted
D3: SMBJ51D-M3/I; D_SMB; MPN SMBJ51D-M3/I
D13: US1B; D_SMA; MPN STPS1H100A
J1: XT30PW-M; AMASS_XT30PW-M; MPN XT30PW-M
J4: Conn_01x02_Pin; PinHeader_1x02_P2.00mm_Vertical
L1, L3: 2.2uH; IND_DFE252012_MUR; MPN DFE252012PD-2R2M=P2
L2: 100uH; IND_6028-WE-LQS_WRE; MPN 74404063101
M1, M2, M3, M4: Conn_01x01_Pin; M3_MOUNT_CORNER
NT1: NetTie_2; NetTie-2_SMD_Pad0.254mm
R1: 42.2k 1%; R_0402_1005Metric; MPN RC0402FR-0742K2L
R2: 69.8k 1%; R_0402_1005Metric; MPN RC0402FR-0769K8L
R3: 80.6k 1%; R_0402_1005Metric; MPN RC0402FR-0780K6L
R4: 22; R_0402_1005Metric; MPN MF-RES-0402-22
R5: 52.3k 1%; R_0402_1005Metric; MPN RC0402FR-0752K3L
R6: 226k 1%; R_0402_1005Metric; MPN RC0402FR-07226KL
R7: 16.2k 1%; R_0402_1005Metric; MPN RC0402FR-0716K2L
R8: DNP; R_0402_1005Metric; not fitted
TP1, TP2, TP3: TestPoint; TestPoint_THTPad_D1.5mm_Drill0.7mm
U1: MAX17760ATC+; 21-0664E_1233-1C_MXM; MPN MAX17760ATC+
U2, U3: TPS629203DRLR; SOT-5x3_DRL0008A_TEX; MPN TPS629203DRLR
VN1: Conn_01x01; POWER_M2.5
VP1: Conn_01x01; POWER_M2.5

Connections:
+3V: C9.1, L3.1, TP3.1, U3.3 (VOS); also elsewhere on the board
+5V: C4.1, D13.1 (K), L1.1, TP1.1, U2.3 (VOS), U3.6 (VIN), U3.7 (EN); also elsewhere on the board
+12V: C7.1, L2.1, R4.2, R6.1, TP2.1, U2.6 (VIN), U2.7 (EN); also elsewhere on the board
/Power Input/5V_IN: D13.2 (A), J4.1
GND: C4.2, C6.2, C7.2, C9.2, J4.2, NT1.2, R1.2, R3.2, R5.2, R7.2, U2.5 (GND), U3.5 (GND); also elsewhere on the board
GNDPWR: C1.2, C2.2, C3.2, C5.2, C8.2, D3.2 (A2), J1.N, NT1.1, R2.2, R8.2, U1.2 (PGND), U1.10 (MODE), U1.11 (SGND), U1.13 (EPAD), VN1.1; also elsewhere on the board
MOUNT_GND: C8.1, M4.1, R8.1
unnamed: C6.1, R4.1, U1.7 (EXTVCC)
unnamed: R6.2, R7.1, U1.8 (FB)
unnamed: L2.2, U1.12 (LX)
unnamed: R2.1, U1.6 (RT/SYNC)
unnamed: C5.1, U1.9 (SS)
unnamed: C3.1, U1.3 (VCC)
unnamed: R3.1, U2.1 (FB/VSET)
unnamed: R1.1, U2.8 (MODE/S-CONF)
unnamed: L1.2, U2.4 (SW)
unnamed: R5.1, U3.8 (MODE/S-CONF)
unnamed: L3.2, U3.4 (SW)
V+: C1.1, C2.1, D3.1 (A1), J1.P, U1.1 (VIN), VP1.1; also elsewhere on the board

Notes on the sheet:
FB: VSET FSW: 2.5MHz Output Discharge: No Mode: Auto PFM
FB: VSET FSW: 2.5MHz Output Discharge: No Mode: FPWM
0.9ms soft start
OPEN = 3.3V
400kHz

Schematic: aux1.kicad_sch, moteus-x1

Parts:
AUX1: SM08B-GHS-TB; CONN_SM08B-GHS-TB_JST; MPN SM08B-GHS-TB(LF)(SN)
AUX1_S1: Conn_01x04; PinHeader_1x04_P1.27mm_Vertical
C41, C42, C43: 1uF; C_0402_1005Metric; MPN MF-CAP-0402-1uF
C44: 0.1uF; C_0402_1005Metric; MPN MF-CAP-0402-0.1uF
D9, D10: BAT41KFILM; SOD-523_STM; MPN BAT41KFILM
R32, R33, R34, R35, R36: 100; R_0402_1005Metric; MPN MF-RES-0402-100
R37, R38: 2k; R_0402_1005Metric; MPN MF-RES-0402-2K
U7: MA600; QFN-16-1EP_3x3mm_P0.5mm_EP1.75x1.75mm; MPN MA600GQE-0000

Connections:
+3V: AUX1.2, AUX1_S1.1, C42.1, C43.1, C44.1, U7.13 (VDD), U7.14 (AVDD); also elsewhere on the board
+5V: AUX1.1, C41.1; also elsewhere on the board
/aux1/AS5047_CS: U7.5 (~CS); also elsewhere on the board
/aux1/AUX1P_A: AUX1.3, R32.1
/aux1/AUX1P_B: AUX1.4, R33.1
/aux1/AUX1P_C: AUX1.5, R34.1
/aux1/AUX1P_D: AUX1.6, AUX1_S1.2, R35.1
/aux1/AUX1P_E: AUX1.7, AUX1_S1.3, R36.1
/aux1/AUX1_A: R32.2, U7.12 (SCLK); also elsewhere on the board
/aux1/AUX1_B: R33.2, U7.7 (MISO); also elsewhere on the board
/aux1/AUX1_C: R34.2, U7.4 (MOSI); also elsewhere on the board
/aux1/AUX1_D: R35.2, R37.2; also elsewhere on the board
/aux1/AUX1_E: R36.2, R38.2; also elsewhere on the board
/aux1/AUX1_I2C_PULLUP: D9.2, D10.2; also elsewhere on the board
GND: AUX1.8, AUX1_S1.4, C41.2, C42.2, C43.2, C44.2, U7.8 (GND), U7.10 (TEST); also elsewhere on the board
unnamed: D9.1, R37.1
unnamed: D10.1, R38.1



Board: 6 copper layers, 56.0 x 56.0 mm, 187 parts (108 on the bottom side), 106 nets.

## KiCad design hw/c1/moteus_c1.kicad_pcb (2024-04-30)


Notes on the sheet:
moteus-n1 (c) mjbots Robotic Systems, LLC - info@mjbots.com - 2023 Licensed under the Apache 2.0 License


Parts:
C28, C29, C30: 0.1uF; C_0402_1005Metric; MPN MF-CAP-0402-0.1uF
R17: 100k 1%; R_0402_1005Metric; MPN RC0402FR-07100KL
R18, R21: 10k 1%; R_0402_1005Metric; MPN RC0402FR-0710KL
R19: 4.7k 1%; R_0402_1005Metric; MPN RC0402FR-074K7L
R20: 47k NTC; R_0402_1005Metric; MPN NCP15WB473F03RC
TEMP1: Conn_01x02_Pin; PinHeader_1x02_P2.00mm_Vertical

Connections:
/VT Sense/VBAT_SENSE: C29.1, R17.2, R19.1; also elsewhere on the board
/VT Sense/VTEMP_FET: C30.1, R20.2, R21.1; also elsewhere on the board
/VT Sense/VTEMP_MOT: C28.1, R18.1, TEMP1.2; also elsewhere on the board
V+: R17.1; also elsewhere on the board


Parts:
D13: LED; LED_0603_1608Metric; MPN MF-LED-0603-RED
D14: LED; LED_0603_1608Metric; MPN MF-LED-0603-GREEN
R29, R30: 560; R_0402_1005Metric; MPN MF-RES-0402-560
TP1: TestPoint; TestPoint_THTPad_D1.0mm_Drill0.5mm

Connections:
/LED Sense/LED1: D13.1 (K); also elsewhere on the board
/LED Sense/LED2: D14.1 (K); also elsewhere on the board
unnamed: D13.2 (A), R29.2
unnamed: D14.2 (A), R30.2


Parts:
C6, C9, C11, C12, C13: 0.1uF; C_0402_1005Metric; MPN MF-CAP-0402-0.1uF
C7: 10uF; C_1206_3216Metric; MPN MF-CAP-1206-10uF
C8: 4.7uF; C_0603_1608Metric; MPN CL10A475KP8NNNC
C10: 1uF; C_0402_1005Metric; MPN MF-CAP-0402-1uF
R2: 2k; R_0402_1005Metric; MPN MF-RES-0402-2K
SWD1: S6B-ZR-SM4A-TF(LF)(SN); JST_S6B-ZR-SM4A-TF(LF)(SN); MPN S6B-ZR-SM4A-TF(LF)(SN)
U3: STM32G474CEU6; UFQFPN-48_7X7X0P55MM; MPN STM32G474CEU6

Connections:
/CAN/CAN_RX: U3.43 (PB5); also elsewhere on the board
/CAN/CAN_TX: U3.44 (PB6); also elsewhere on the board
/Current Sense/FCUR1: U3.11 (PA3); also elsewhere on the board
/Current Sense/FCUR2: U3.14 (PA6); also elsewhere on the board
/Current Sense/FCUR3: U3.18 (PB1); also elsewhere on the board
/Gate Driver/DRV8323_CS: U3.17 (PB0); also elsewhere on the board
/Gate Driver/DRV8323_FAULT: U3.26 (PB13); also elsewhere on the board
/Gate Driver/DRV8323_MOSI: U3.2 (PC13); also elsewhere on the board
/Gate Driver/DRV8323_SCLK: U3.39 (PC10); also elsewhere on the board
/Gate Driver/MOTOR1: U3.8 (PA0); also elsewhere on the board
/Gate Driver/MOTOR2: U3.9 (PA1); also elsewhere on the board
/Gate Driver/MOTOR3: U3.10 (PA2); also elsewhere on the board
/Gate Driver/MOTOR_ENABLE: U3.3 (PC14-OSC32_IN); also elsewhere on the board
/Gate Driver/MOTOR_HIZ: U3.4 (PC15-OSC32_OUT); also elsewhere on the board
/LED Sense/LED1: U3.28 (PB15); also elsewhere on the board
/LED Sense/LED2: U3.29 (PC6); also elsewhere on the board
/VT Sense/VBAT_SENSE: U3.31 (PA9); also elsewhere on the board
/VT Sense/VTEMP_FET: U3.25 (PB12); also elsewhere on the board
/VT Sense/VTEMP_MOT: U3.30 (PA8); also elsewhere on the board
/aux1/AS5047_CS: U3.19 (PB2); also elsewhere on the board
/aux1/AUX1_A: U3.13 (PA5); also elsewhere on the board
/aux1/AUX1_B: U3.42 (PB4); also elsewhere on the board
/aux1/AUX1_C: U3.15 (PA7); also elsewhere on the board
/aux1/AUX1_D: U3.38 (PA15); also elsewhere on the board
/aux1/AUX1_E: U3.41 (PB3), U3.47 (PB9); also elsewhere on the board
/aux2/AUX2_A: U3.6 (PF1-OSC_OUT); also elsewhere on the board
/aux2/AUX2_B: U3.5 (PF0-OSC_IN), U3.32 (PA10); also elsewhere on the board
/aux2/AUX2_C: U3.16 (PC4), U3.33 (PA11); also elsewhere on the board
/aux2/AUX2_D: U3.45 (PB7); also elsewhere on the board
/aux2/AUX2_I2C_PULLUP: U3.34 (PA12); also elsewhere on the board
/stm32g4/AUX1_I2C_PULLUP: U3.46 (PB8-BOOT0)
/stm32g4/NRST: C6.1, SWD1.2, U3.7 (PG10-NRST)
/stm32g4/SWCLK: SWD1.5, U3.37 (PA14)
/stm32g4/SWDIO: SWD1.3, U3.36 (PA13)

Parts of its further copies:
R31: 2k; R_0402_1005Metric; MPN MF-RES-0402-2K

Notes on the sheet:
PB10 is disconnected on r4.5/r4.8/r4.11 PB10 is RS422 receive enable output on n1 It is tied to ground here to detect we are a c1 board
PCB rev divider HI / LO r1.0 - open / open
AUX1_A (but only for external)


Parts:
C19: 0.1uF 100V; C_1206_3216Metric; MPN 12061C104KAT2A
D2, D3: BAT41KFILM; SOD-523_STM; MPN BAT41KFILM; not fitted
D4: BAT41KFILM; SOD-523_STM; MPN BAT41KFILM
NT2, NT3: NetTie_2; NetTie-2_SMD_Pad0.254mm
Q1, Q2: TPN19008QM_LQ; TSON Advance_TOS; MPN TPN19008QM,LQ
R4, R5: 0; R_0402_1005Metric; MPN MF-RES-0402-0
R6: 2mOhm; R_0805_2012Metric; MPN CSSH0805FT2L00
X1: Conn_01x01; POWER_M2.5

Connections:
/Gate Driver/GHA: D2.1, R4.1; also elsewhere on the board
/Gate Driver/GLA: D3.1, R5.1; also elsewhere on the board
/H Bridge A/GHX_Q: D2.2, Q1.4 (GATE), R4.2
/H Bridge A/GLX_Q: D3.2, D4.1, Q2.4 (GATE), R5.2
/H Bridge A/OUTX: Q1.1 (SOURCE), Q1.2 (SOURCE), Q1.3 (SOURCE), Q2.5 (DRAIN), Q2.6 (DRAIN), Q2.7 (DRAIN), Q2.8 (DRAIN), X1.1; also elsewhere on the board
/H Bridge A/SPX_Q: C19.2, NT2.2, Q2.1 (SOURCE), Q2.2 (SOURCE), Q2.3 (SOURCE), R6.1
/H Bridge A/SXX_N: NT3.1; also elsewhere on the board
/H Bridge A/SXX_P: NT2.1; also elsewhere on the board
GNDPWR: D4.2, NT3.2, R6.2; also elsewhere on the board
V+: C19.1, Q1.5 (DRAIN), Q1.6 (DRAIN), Q1.7 (DRAIN), Q1.8 (DRAIN); also elsewhere on the board

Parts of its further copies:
C20, C21: 0.1uF 100V; C_1206_3216Metric; MPN 12061C104KAT2A
D5, D6, D8, D9: BAT41KFILM; SOD-523_STM; MPN BAT41KFILM; not fitted
D7, D10: BAT41KFILM; SOD-523_STM; MPN BAT41KFILM
NT4, NT5, NT6, NT7: NetTie_2; NetTie-2_SMD_Pad0.254mm
Q3, Q4, Q5, Q6: TPN19008QM_LQ; TSON Advance_TOS; MPN TPN19008QM,LQ
R7, R8, R10, R11: 0; R_0402_1005Metric; MPN MF-RES-0402-0
R9, R12: 2mOhm; R_0805_2012Metric; MPN CSSH0805FT2L00
X2, X3: Conn_01x01; POWER_M2.5

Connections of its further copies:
/Gate Driver/GHB: D5.1, R7.1; also elsewhere on the board
/Gate Driver/GHC: D8.1, R10.1; also elsewhere on the board
/Gate Driver/GLB: D6.1, R8.1; also elsewhere on the board
/Gate Driver/GLC: D9.1, R11.1; also elsewhere on the board
/H Bridge B/GHX_Q: D5.2, Q3.4 (GATE), R7.2
/H Bridge B/GLX_Q: D6.2, D7.1, Q4.4 (GATE), R8.2
/H Bridge B/OUTX: Q3.1 (SOURCE), Q3.2 (SOURCE), Q3.3 (SOURCE), Q4.5 (DRAIN), Q4.6 (DRAIN), Q4.7 (DRAIN), Q4.8 (DRAIN), X2.1; also elsewhere on the board
/H Bridge B/SPX_Q: C20.2, NT4.2, Q4.1 (SOURCE), Q4.2 (SOURCE), Q4.3 (SOURCE), R9.1
/H Bridge B/SXX_N: NT5.1; also elsewhere on the board
/H Bridge B/SXX_P: NT4.1; also elsewhere on the board
/H Bridge C/GHX_Q: D8.2, Q5.4 (GATE), R10.2
/H Bridge C/GLX_Q: D9.2, D10.1, Q6.4 (GATE), R11.2
/H Bridge C/OUTX: Q5.1 (SOURCE), Q5.2 (SOURCE), Q5.3 (SOURCE), Q6.5 (DRAIN), Q6.6 (DRAIN), Q6.7 (DRAIN), Q6.8 (DRAIN), X3.1; also elsewhere on the board
/H Bridge C/SPX_Q: C21.2, NT6.2, Q6.1 (SOURCE), Q6.2 (SOURCE), Q6.3 (SOURCE), R12.1
/H Bridge C/SXX_N: NT7.1; also elsewhere on the board
/H Bridge C/SXX_P: NT6.1; also elsewhere on the board
GNDPWR: D7.2, D10.2, NT5.2, NT7.2, R9.2, R12.2; also elsewhere on the board
V+: C20.1, C21.1, Q3.5 (DRAIN), Q3.6 (DRAIN), Q3.7 (DRAIN), Q3.8 (DRAIN), Q5.5 (DRAIN), Q5.6 (DRAIN), Q5.7 (DRAIN), Q5.8 (DRAIN); also elsewhere on the board


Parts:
C38, C39, C40, C41, C42, C43, C44, C45, C46, C47, C48, C49: 4.7uF 100V; C_1206_3216Metric; MPN GRJ31CC72A475KE01K

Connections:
GNDPWR: C38.2, C39.2, C40.2, C41.2, C42.2, C43.2, C44.2, C45.2, C46.2, C47.2, C48.2, C49.2; also elsewhere on the board
V+: C38.1, C39.1, C40.1, C41.1, C42.1, C43.1, C44.1, C45.1, C46.1, C47.1, C48.1, C49.1; also elsewhere on the board


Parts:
AUX2: SM07B-GHS-TB(LF)(SN); JST_SM07B-GHS-TB(LF)(SN); MPN SM07B-GHS-TB(LF)(SN)
AUX2H1: Conn_02x04_Odd_Even; PinHeader_2x04_P1.27mm_Vertical
C31, C32: 1uF; C_0402_1005Metric; MPN MF-CAP-0402-1uF
C33, C34, C35, C36: DNP; C_0402_1005Metric; not fitted
D11, D12: BAT41KFILM; SOD-523_STM; MPN BAT41KFILM
R22, R23: 2k; R_0402_1005Metric; MPN MF-RES-0402-2K
R24, R25, R26, R27: 100; R_0402_1005Metric; MPN MF-RES-0402-100

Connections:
+5V: AUX2.1, AUX2H1.2, C31.1; also elsewhere on the board
/aux2/AUX2P_B: AUX2.4, AUX2H1.5, R25.1
/aux2/AUX2P_C: AUX2.5, AUX2H1.3, R26.1
/aux2/AUX2P_D: AUX2.6, AUX2H1.1, R27.1
/aux2/AUX2_A: C36.1, R24.2; also elsewhere on the board
/aux2/AUX2_B: C35.1, R22.2, R25.2; also elsewhere on the board
/aux2/AUX2_C: C34.1, R23.2, R26.2; also elsewhere on the board
/aux2/AUX2_D: C33.1, R27.2; also elsewhere on the board
/aux2/AUX2_I2C_PULLUP: D11.2, D12.2; also elsewhere on the board
unnamed: D11.1, R22.1
unnamed: D12.1, R23.1


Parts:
C23, C24, C25: 1000pF; C_0402_1005Metric; MPN MF-CAP-0402-1nF
R13, R14, R15: 22; R_0402_1005Metric; MPN MF-RES-0402-22

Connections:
/Current Sense/CUR1: R13.1; also elsewhere on the board
/Current Sense/CUR2: R14.1; also elsewhere on the board
/Current Sense/CUR3: R15.1; also elsewhere on the board
/Current Sense/FCUR1: C23.1, R13.2; also elsewhere on the board
/Current Sense/FCUR2: C24.1, R14.2; also elsewhere on the board
/Current Sense/FCUR3: C25.1, R15.2; also elsewhere on the board

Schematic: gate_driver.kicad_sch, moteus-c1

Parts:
C14: 1uF 25V; C_0603_1608Metric; MPN C1608X7R1E105K080AE
C15: 0.1uF 100V; C_0603_1608Metric; MPN GCJ188R72A104KA01D
C16: 47nF 100V; C_0603_1608Metric; MPN C0603X473K1RAC7867
C17: 1uF; C_0402_1005Metric; MPN MF-CAP-0402-1uF
C18: 1uF; C_0603_1608Metric; MPN MF-CAP-0603-1uF
R2, R3: 2k; R_0402_1005Metric; MPN MF-RES-0402-2K
U4: DRV8323SRTAR; RTA0040B; MPN DRV8323SRTAR

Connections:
/Current Sense/CUR1: U4.21 (SOC); also elsewhere on the board
/Current Sense/CUR2: U4.22 (SOB); also elsewhere on the board
/Current Sense/CUR3: U4.23 (SOA); also elsewhere on the board
/Gate Driver/DRV8323_CS: U4.29 (GAIN_SCS_N); also elsewhere on the board
/Gate Driver/DRV8323_FAULT: R3.2, U4.25 (FAULT_N); also elsewhere on the board
/Gate Driver/DRV8323_MOSI: U4.27 (IDRIVE_SDI); also elsewhere on the board
/Gate Driver/DRV8323_SCLK: U4.28 (VDS_SCLK); also elsewhere on the board
/Gate Driver/GHA: U4.6 (GHA); also elsewhere on the board
/Gate Driver/GHB: U4.15 (GHB); also elsewhere on the board
/Gate Driver/GHC: U4.16 (GHC); also elsewhere on the board
/Gate Driver/GLA: U4.8 (GLA); also elsewhere on the board
/Gate Driver/GLB: U4.13 (GLB); also elsewhere on the board
/Gate Driver/GLC: U4.18 (GLC); also elsewhere on the board
/Gate Driver/MOTOR1: U4.34 (INHA); also elsewhere on the board
/Gate Driver/MOTOR2: U4.36 (INHB); also elsewhere on the board
/Gate Driver/MOTOR3: U4.38 (INHC); also elsewhere on the board
/Gate Driver/MOTOR_ENABLE: U4.30 (ENABLE); also elsewhere on the board
/Gate Driver/MOTOR_HIZ: U4.35 (INLA), U4.37 (INLB), U4.39 (INLC); also elsewhere on the board
/H Bridge A/OUTX: U4.7 (SHA); also elsewhere on the board
/H Bridge A/SXX_N: U4.10 (SNA); also elsewhere on the board
/H Bridge A/SXX_P: U4.9 (SPA); also elsewhere on the board
/H Bridge B/OUTX: U4.14 (SHB); also elsewhere on the board
/H Bridge B/SXX_N: U4.11 (SNB); also elsewhere on the board
/H Bridge B/SXX_P: U4.12 (SPB); also elsewhere on the board
/H Bridge C/OUTX: U4.17 (SHC); also elsewhere on the board
/H Bridge C/SXX_N: U4.20 (SNC); also elsewhere on the board
/H Bridge C/SXX_P: U4.19 (SPC); also elsewhere on the board
GNDPWR: C15.1, U4.40 (PGND), U4.41 (PAD); also elsewhere on the board
unnamed: C16.2, U4.2 (CPH)
unnamed: C16.1, U4.1 (CPL)
unnamed: C17.2, U4.33 (DVDD)
unnamed: C14.2, U4.3 (VCP)
V+: C14.1, C15.2, U4.4 (VM), U4.5 (VDRAIN); also elsewhere on the board

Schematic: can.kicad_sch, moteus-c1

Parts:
C26, C27: 0.1uF; C_0402_1005Metric; MPN MF-CAP-0402-0.1uF
CAN1: S3B-PH-SM4-TB(LF)(SN); JST_S3B-PH-SM4-TB(LF)(SN); MPN S3B-PH-SM4-TB(LF)(SN)
CAN_DBG1: Conn_01x03_Pin; PinHeader_1x03_P2.00mm_Vertical
R16: 120; R_0805_2012Metric; MPN RC0805FR-07120RL; not fitted
U5: TCAN1057AEV-Q1; SOIC-8_3.9x4.9mm_P1.27mm; MPN TCAN1057AEVDRQ1

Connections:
+5V: C27.1, U5.3 (VCC); also elsewhere on the board
/CAN/CAN_N: CAN1.2, CAN_DBG1.2, R16.2, U5.6 (CANL)
/CAN/CAN_P: CAN1.1, CAN_DBG1.1, R16.1, U5.7 (CANH)
/CAN/CAN_RX: U5.4 (RXD); also elsewhere on the board
/CAN/CAN_TX: U5.1 (TXD); also elsewhere on the board

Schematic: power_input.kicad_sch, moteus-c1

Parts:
C1: 1uF 100V; C_0805_2012Metric; MPN GCM21BC72A105KE36L
C2: 22uF; C_1206_3216Metric; MPN GRM31CR71A226KE15L
C3, C4: 1uF; C_0402_1005Metric; MPN MF-CAP-0402-1uF
C5: 1uF; C_0603_1608Metric; MPN MF-CAP-0603-1uF
D1: SMBJ51D-M3/I; D_SMB; MPN SMBJ51D-M3/I
J1: XT30PW-M; AMASS_XT30PW-M; MPN XT30PW-M
L1: 47uH; IND_4018-WE-LQS_WRE; MPN 74404042470
NT1: NetTie_2; NetTie-2_SMD_Pad0.254mm
R1: 0; R_0402_1005Metric; MPN MF-RES-0402-0
U1: MAX15062BATA+T; 21-0487A_MXM; MPN MAX15062BATA+T
U2: TLV70233DSER; DSE0006A; MPN TLV70233DSER
VN1: Conn_01x01; POWER_M2.5
VP1: Conn_01x01; POWER_M2.5

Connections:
+5V: C2.1, C3.1, L1.1, U1.4 (FB/VOUT), U2.1 (IN); also elsewhere on the board
GNDPWR: C1.2, C5.2, D1.2 (A2), J1.N, NT1.1, VN1.1; also elsewhere on the board
unnamed: L1.2, U1.8 (LX)
unnamed: R1.1, U1.5 (MODE)
unnamed: C5.1, U1.3 (VCC)
V+: C1.1, D1.1 (A1), J1.P, U1.1 (VIN), U1.2 (EN/UVLO), VP1.1; also elsewhere on the board

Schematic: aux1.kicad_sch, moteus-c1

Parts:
AUX1: Conn_01x04; PinHeader_1x04_P1.27mm_Vertical
C37: 0.1uF; C_0402_1005Metric; MPN MF-CAP-0402-0.1uF
R24: 100; R_0402_1005Metric; MPN MF-RES-0402-100
R28: 0; R_0402_1005Metric; MPN MF-RES-0402-0
U6: AS5047P-ATSM; TSSOP14_OSM; MPN AS5047P-ATSM

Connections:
/aux1/AS5047_CS: U6.1 (CSn); also elsewhere on the board
/aux1/AUX1_A: U6.2 (CLK); also elsewhere on the board
/aux1/AUX1_B: U6.3 (MISO); also elsewhere on the board
/aux1/AUX1_C: U6.4 (MOSI); also elsewhere on the board
/aux2/AUX2_A: R24.2; also elsewhere on the board
unnamed: R28.1, U6.11 (VDD)

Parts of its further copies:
R34, R35: 100; R_0402_1005Metric; MPN MF-RES-0402-100

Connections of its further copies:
/aux1/AUX1_D: R34.2; also elsewhere on the board
/aux1/AUX1_E: R35.2; also elsewhere on the board

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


Board: 4 copper layers, 38.0 x 38.0 mm, 135 parts (61 on the bottom side), 88 nets.

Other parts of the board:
MOUNT1, MOUNT2, MOUNT3, MOUNT4: M2.5_MOUNT
R32, R33: DNP; R_0402_1005Metric

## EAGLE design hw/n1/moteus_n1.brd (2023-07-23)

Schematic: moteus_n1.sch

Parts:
A: PAD16AWG_TERM; 16AWG_TERM
AUX1: SM08B-GHS-TB(LF)(SN); JST_SM08B-GHS-TB(LF)(SN); MPN SM08B-GHS-TB(LF)(SN)
AUX2: SM07B-GHS-TB(LF)(SN); JST_SM07B-GHS-TB(LF)(SN); MPN SM07B-GHS-TB(LF)(SN)
AUX2H: PH2X4
B: PAD16AWG_TERM; 16AWG_TERM
C: PAD16AWG_TERM; 16AWG_TERM
C1, C19, C20, C21, C22, C25, C26, C27, C28, C29: DNP; C0402
C2: 1uF 100V; C0805; MPN GCM21BC72A105KE36L
C3, C17, C18, C23\, C24: 1uF; C0603; MPN MF-CAP-0603-1uF
C4: 22uF; C1206; MPN GRM31CR71A226KE15L
C5, C11, C23, C41: 1uF; C0402; MPN MF-CAP-0402-1uF
C6: 22uF; C1206; MPN CL31B226KPHNNNE
C7, C8, C9, C12, C14, C15, C16, C30, C32, C33, C42, C87: 0.1uF; C0402; MPN MF-CAP-0402-0.1uF
C10: 4.7uF; C0603; MPN CL10A475KP8NNNC
C13: 10uF; C1206; MPN MF-CAP-1206-10uF
C31: 0.01uF; C0402; MPN MF-CAP-0402-0.01uF
C34, C35, C36: 1000pF; C0402; MPN MF-CAP-0402-1nF
C37, C39: 0.1uF 100V; C0603; MPN GCJ188R72A104KA01D
C38, C40: 1uF; C0603; MPN C1608X7R1E105K080AE
C43: 0.47uF 100V; C0805; MPN 08051C474KAT2A
C44, C45, C46: 0.1uF 100V; C1206; MPN 12061C104KAT2A
C47, C48: 4.7uF 100V; C1206; MPN GRJ31CC72A475KE01K
C49, C50, C51, C52, C53, C54, C55, C56, C57, C58, C59, C60, C61, C62, C63, C64, C65, C66, C67, C68, C69, C70, C71, C72, C73, C74, C75, C76, C77, C78, C79, C80, C81, C82, C83, C84, C85, C86: 4.7uF 100V; C1206_NOBORDER; MPN GRJ31CC72A475KE01K
CAN1, CAN2: JST-PH3; JST_S3B-PH-SM4-TB(LF)(SN); MPN S3B-PH-SM4-TB(LF)(SN)
CAN_DBG: 1X3
D1: MF-LED-0603-RED; LED0603
D2: MF-LED-0603-RED; LED0603; MPN MF-LED-0603-GREEN
D3, D4, D5, D6, D7, D8, D9, D10, D11, D13, D14, D15, D16: BAT41KFILM; SODFL1608X70N; MPN BAT41KFILM
D12: DIODE-DO214AA; DO214AA; MPN SMBJ51D-M3/I
D33, D50: PAD24AWG_PAD; 24AWG_PAD
DAC: PAD24AWG_PAD; 24AWG_PAD
DG1: PAD24AWG_PAD; 24AWG_PAD
DTR: PAD24AWG_PAD; 24AWG_PAD
DTX: PAD24AWG_PAD; 24AWG_PAD
J1, J2: XT30XT30PW_MALE; XT30PW_MALE; MPN XT30PW-M
J3: SM06B-GHS-TB(LF)(SN); JST_SM06B-GHS-TB(LF)(SN); MPN SM06B-GHS-TB(LF)(SN)
L1: SRN4018-220M; IND_BOURNS_SRN4018; MANUFACTURER_PART_NUMBER 74404042470
L2: 74479887222A; IND_1008_WE-PMI_WRE; MPN 74479887222A
M1, M2, M3, M4: MOUNT; M2.5MOUNT
Q1, Q3, Q5: TPH1R204PL_VIAS; SOP_ADVANCE_8_VIAS; MPN TPH2R408QM,L1Q
Q2, Q4, Q6: TPH1R204PLSOP_ADVANCE_8; SOP_ADVANCE_8; MPN TPH2R408QM,L1Q
R1, R3: DNP; R0402
R2, R15: 100k 1%; R0402; MPN RC0402FR-07100KL
R4, R5, R8, R9, R10, R11, R12, R13, R14: 100; R0402; MPN MF-RES-0402-100
R6, R7, R25, R26, R33, R34: 2k; R0402; MPN MF-RES-0402-2K
R16: 4.7k 1%; R0402; MPN RC0402FR-074K7L
R17: 47k NTC; R0402; MPN NCP15WB473F03RC
R18, R19: 10k 1%; R0402; MPN RC0402FR-0710KL
R20, R21: 560; R0402; MPN MF-RES-0402-560
R22, R23, R24: 22; R0402; MPN MF-RES-0402-22
R27, R28, R30, R31, R32: 7.5; R0402; MPN RC0402FR-077R5L
R29: 7.5; R0805; MPN RC0805FR-077R5L
R35, R36: 120; R0402; MPN RC0402FR-07120RL
R37: DNP; R0805
R38, R39, R40: 0; R0402; MPN MF-RES-0402-0
RA: 0.5mOhm 1% 2W; M1206; MPN HCS1206FTL500
RB: 0.5mOhm 1% 2W; M1206; MPN HCS1206FTL500
RC: 0.5mOhm 1% 2W; M1206; MPN HCS1206FTL500
SH1, SH2, SH3: SHORTT5; SHORT_TOP-50
SH4: SHORTMEDIUM; SHORT_TOP-MEDIUM
SWD: JST-ZH6; JST_S6B-ZR-SM4A-TF(LF)(SN); MPN S6B-ZR-SM4A-TF(LF)(SN)
TEMP: 1X2
U1: MAX15062BATA+T; 21-0487A_MXM; MANUFACTURER_PART_NUMBER MAX15062BATA+T
U2: ADP5301ACBZ-4-R7; BGA9C50P3X3_165X187X66; MPN ADP5301ACBZ-4-R7
U3: STM32G474CEU6; QFN50P700X700X60-49N; MPN STM32G474CEU6
U4: TCAN1042HGV; SOIC8; MPN TCAN1057AEVDRQ1
U5: AS5147; TSSOP14; MPN AS5047P-ATSM
U7: DRV8353S; WQFN-40; MPN DRV8353FSRTAR
U8: SN65HVD35DR; D14
VN: PAD16AWG_TERM; 16AWG_TERM
VP: PAD16AWG_TERM; 16AWG_TERM

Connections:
+3V3: AUX1.2, AUX2.2, AUX2H.P$4 (4), C6.P$1, C7.P$1, C8.P$1, C10.P$1, C11.P$1, C12.P$1, C13.P$2, C15.P$1, C16.P$1, C18.P$1, C23.P$1, C24.P$1, C30.P$1, C42.P$2, C87.P$1, D33.P$1, L2.1, R2.P$2, R17.P$1, R20.P$1, R21.P$1, R25.P$1, R26.P$1, R40.P$2, SWD.6, TEMP.1, U2.C2 (FB), U3.1 (VBAT), U3.20 (VREF+), U3.21 (VDDA), U3.23 (VDD_1), U3.35 (VDD_2), U3.48 (VDD_3), U4.5 (VIO), U5.12 (VDD3V), U7.24 (VREF), U8.13 (VCC_2), U8.14 (VCC)
+5V: AUX1.1, AUX2.1, AUX2H.P$2 (2), C4.P$1, C5.P$1, C14.P$1, C17.P$1, C23\.P$1, D50.P$1, J3.1, L1.1, R39.P$2, U1.4 (FB/VOUT), U2.A2 (PVIN), U2.A3 (EN), U4.3 (VCC)
AS5047_CS: U3.19 (PB2), U5.1 (CS/)
AUX1P_A: AUX1.3, R10.P$1
AUX1P_B: AUX1.4, R11.P$1
AUX1P_C: AUX1.5, R12.P$1
AUX1P_D: AUX1.6, R13.P$1
AUX1P_E: AUX1.7, R14.P$1
AUX1_A: C29.P$1, R10.P$2, U3.13 (PA5), U3.27 (PB14), U5.2 (CLK)
AUX1_B: C28.P$1, R11.P$2, U3.42 (PB4), U5.3 (MISO)
AUX1_C: C27.P$1, R12.P$2, U3.15 (PA7), U5.4 (MOSI)
AUX1_D: C26.P$1, DTR.P$1, R13.P$2, R34.P$2, U3.38 (PA15), U8.2 (R)
AUX1_E: C25.P$1, DTX.P$1, R14.P$2, R33.P$2, U3.41 (PB3), U3.47 (PB9), U8.5 (D)
AUX1_I2C_PULLUP: D13.2 (A), D14.2 (A), U3.46 (PB8-BOOT0)
AUX2P_A: AUX2.3, AUX2H.P$7 (7), AUX2H.P$8 (8), R4.P$1
AUX2P_B: AUX2.4, AUX2H.P$5 (5), R5.P$1
AUX2P_C: AUX2.5, AUX2H.P$3 (3), R9.P$1
AUX2P_D: AUX2.6, AUX2H.P$1 (1), R8.P$1
AUX2_A: C22.P$1, R4.P$2, U3.6 (PF1-OSC_OUT)
AUX2_B: C21.P$1, R5.P$2, R6.P$2, U3.5 (PF0-OSC_IN), U3.32 (PA10)
AUX2_C: C20.P$1, R7.P$2, R9.P$2, U3.16 (PC4), U3.33 (PA11)
AUX2_D: C19.P$1, R8.P$2, U3.45 (PB7)
AUX2_I2C_PULLUP: D15.2 (A), D16.2 (A), U3.34 (PA12)
CAN_N: CAN1.2, CAN2.2, CAN_DBG.2, R37.P$2, U4.6 (CANL)
CAN_P: CAN1.1, CAN2.1, CAN_DBG.1, R37.P$1, U4.7 (CANH)
CAN_RX: U3.43 (PB5), U4.4 (RXD)
CAN_TX: U3.44 (PB6), U4.1 (TXD)
CUR1: R22.P$1, U7.23 (SOA)
CUR2: R23.P$1, U7.22 (SOB)
CUR3: R24.P$1, U7.21 (SOC)
DAC: DAC.P$1, R2.P$1, R3.P$2, U3.12 (PA4)
DRV8323_CS: U3.17 (PB0), U7.30 (CS)
DRV8323_MISO: R25.P$2, U3.40 (PC11), U7.27 (MISO)
DRV8323_MOSI: U3.2 (PC13), U7.28 (MOSI)
DRV8323_SCLK: U3.39 (PC10), U7.29 (SCLK)
FCUR1: C34.P$1, R22.P$2, U3.11 (PA3)
FCUR2: C35.P$1, R23.P$2, U3.14 (PA6)
FCUR3: C36.P$1, R24.P$2, U3.18 (PB1)
GHA: D5.1 (K), R28.P$1, U7.6 (GHA)
GHA_D: D5.2 (A), Q1.4 (G), R28.P$2
GHB: D8.1 (K), R30.P$1, U7.15 (GHB)
GHB_D: D8.2 (A), Q3.4 (G), R30.P$2
GHC: D11.1 (K), R32.P$1, U7.16 (GHC)
GHC_D: D11.2 (A), Q5.4 (G), R32.P$2
GLA: D3.1 (K), R27.P$1, U7.8 (GLA)
GLA_D: D3.2 (A), D4.1 (K), Q2.4 (G), R27.P$2
GLB: D6.1 (K), R29.P$1, U7.13 (GLB)
GLB_D: D6.2 (A), D7.1 (K), Q4.4 (G), R29.P$2
GLC: D9.1 (K), R31.P$1, U7.18 (GLC)
GLC_D: D9.2 (A), D10.1 (K), Q6.4 (G), R31.P$2
GND: AUX1.8, AUX2.7, AUX2H.P$6 (6), C3.P$2, C4.P$2, C5.P$2, C6.P$2, C7.P$2, C8.P$2, C9.P$2, C10.P$2, C11.P$2, C12.P$2, C13.P$1, C14.P$2, C15.P$2, C16.P$2, C17.P$2, C18.P$2, C19.P$2, C20.P$2, C21.P$2, C22.P$2, C23.P$2, C23\.P$2, C24.P$2, C25.P$2, C26.P$2, C27.P$2, C28.P$2, C29.P$2, C30.P$2, C31.P$2, C32.P$2, C33.P$2, C34.P$2, C35.P$2, C36.P$2, C42.P$1, C87.P$2, CAN1.3, CAN2.3, CAN_DBG.3, DG1.P$1, J3.6, R3.P$1, R16.P$1, R18.P$2, R19.P$2, R38.P$1, SH4.2, SWD.4, U1.7 (GND), U2.B1 (PGND), U2.B2 (AGND), U3.49 (THERMALPAD), U4.2 (GND), U4.8 (STB), U5.5 (TEST), U5.13 (GND), U7.25 (AGND), U8.6 (GND_2), U8.7 (GND)
LED1: D1.CATHODE, U3.28 (PB15)
LED2: D2.CATHODE, U3.29 (PC6)
MOTOR1: U3.8 (PA0), U7.32 (INHA)
MOTOR2: U3.9 (PA1), U7.34 (INHB)
MOTOR3: U3.10 (PA2), U7.36 (INHC)
MOTOR_ENABLE: U3.3 (PC14-OSC32_IN), U7.31 (ENABLE)
MOTOR_FAULT: R26.P$2, U3.26 (PB13), U7.26 (FAULT)
MOTOR_HIZ: U3.4 (PC15-OSC32_OUT), U7.33 (INLA), U7.35 (INLB), U7.37 (INLC)
unnamed: C1.P$1, M3.P$1, R1.P$1
unnamed: C40.P$2, U7.40 (VGLS)
unnamed: R40.P$1, U5.11 (VDD5V)
unnamed: C3.P$1, U1.3 (VCC)
unnamed: L2.2, U2.A1 (SW)
unnamed: C39.P$2, U7.1 (CPL)
unnamed: C39.P$1, U7.2 (CPH)
unnamed: C38.P$2, U7.5 (VCP)
unnamed: C41.P$2, U7.38 (DVDD)
unnamed: D1.ANODE, R20.P$2
unnamed: D2.ANODE, R21.P$2
unnamed: R38.P$2, U1.5 (MODE)
unnamed: D14.1 (K), R34.P$1
unnamed: R39.P$1, U2.B3 (SYNC/_MODE)
unnamed: D13.1 (K), R33.P$1
unnamed: D15.1 (K), R6.P$1
unnamed: D16.1 (K), R7.P$1
NRST: C9.P$1, SWD.2, U3.7 (PG10-NRST)
RS422_A: J3.2, R35.P$2, U8.12 (A)
RS422_B: J3.3, R35.P$1, U8.11 (B)
RS422_DE: U3.24 (PB11), U8.4 (DE)
RS422_RE: U3.22 (PB10), U8.3 (!RE)
RS422_Y: J3.4, R36.P$2, U8.9 (Y)
RS422_Z: J3.5, R36.P$1, U8.10 (Z)
SHA: A.1, A.2, A.3, A.4, A.5, A.6, A.7, A.8, A.9, A.10, A.11, A.12, A.13, Q1.1 (S), Q1.2 (S), Q1.3 (S), Q2.5 (D), Q2.6 (D), Q2.7 (D), Q2.8 (D), Q2.PAD (D), U7.7 (SHA)
SHB: B.1, B.2, B.3, B.4, B.5, B.6, B.7, B.8, B.9, B.10, B.11, B.12, B.13, Q3.1 (S), Q3.2 (S), Q3.3 (S), Q4.5 (D), Q4.6 (D), Q4.7 (D), Q4.8 (D), Q4.PAD (D), U7.14 (SHB)
SHC: C.1, C.2, C.3, C.4, C.5, C.6, C.7, C.8, C.9, C.10, C.11, C.12, C.13, Q5.1 (S), Q5.2 (S), Q5.3 (S), Q6.5 (D), Q6.6 (D), Q6.7 (D), Q6.8 (D), Q6.PAD (D), U7.17 (SHC)
SWCLK: SWD.5, U3.37 (PA14)
SWDIO: SWD.3, U3.36 (PA13)
SXA_N: SH1.1, U7.10 (SNA)
SXA_P: C44.P$2, Q2.1 (S), Q2.2 (S), Q2.3 (S), RA.2, U7.9 (SPA)
SXB_N: SH2.1, U7.11 (SNB)
SXB_P: C45.P$2, Q4.1 (S), Q4.2 (S), Q4.3 (S), RB.2, U7.12 (SPB)
SXC_N: SH3.1, U7.20 (SNC)
SXC_P: C46.P$2, Q6.1 (S), Q6.2 (S), Q6.3 (S), RC.2, U7.19 (SPC)
V+: C2.P$1, C37.P$1, C38.P$1, C43.P$1, C44.P$1, C45.P$1, C46.P$1, C47.P$1, C48.P$1, C49.P$1, C50.P$1, C51.P$1, C52.P$1, C53.P$1, C54.P$1, C55.P$1, C56.P$1, C57.P$1, C58.P$1, C59.P$1, C60.P$1, C61.P$1, C62.P$1, C63.P$1, C64.P$1, C65.P$1, C66.P$1, C67.P$1, C68.P$1, C69.P$1, C70.P$1, C71.P$1, C72.P$1, C73.P$1, C74.P$1, C75.P$1, C76.P$1, C77.P$1, C78.P$1, C79.P$1, C80.P$1, C81.P$1, C82.P$1, C83.P$1, C84.P$1, C85.P$1, C86.P$1, D12.C, J1.1, J2.1, Q1.5 (D), Q1.6 (D), Q1.7 (D), Q1.8 (D), Q1.PAD (D), Q3.5 (D), Q3.6 (D), Q3.7 (D), Q3.8 (D), Q3.PAD (D), Q5.5 (D), Q5.6 (D), Q5.7 (D), Q5.8 (D), Q5.PAD (D), R15.P$2, U1.1 (VIN), U1.2 (EN/UVLO), U7.3 (VM), U7.4 (VDRAIN), VP.1, VP.2, VP.3, VP.4, VP.5, VP.6, VP.7, VP.8, VP.9, VP.10, VP.11, VP.12, VP.13
V-: C1.P$2, C2.P$2, C37.P$2, C40.P$1, C41.P$1, C43.P$2, C47.P$2, C48.P$2, C49.P$2, C50.P$2, C51.P$2, C52.P$2, C53.P$2, C54.P$2, C55.P$2, C56.P$2, C57.P$2, C58.P$2, C59.P$2, C60.P$2, C61.P$2, C62.P$2, C63.P$2, C64.P$2, C65.P$2, C66.P$2, C67.P$2, C68.P$2, C69.P$2, C70.P$2, C71.P$2, C72.P$2, C73.P$2, C74.P$2, C75.P$2, C76.P$2, C77.P$2, C78.P$2, C79.P$2, C80.P$2, C81.P$2, C82.P$2, C83.P$2, C84.P$2, C85.P$2, C86.P$2, D4.2 (A), D7.2 (A), D10.2 (A), D12.A, J1.2, J2.2, R1.P$2, RA.1, RB.1, RC.1, SH1.2, SH2.2, SH3.2, SH4.1, U7.39 (GND), U7.PAD, VN.1, VN.2, VN.3, VN.4, VN.5, VN.6, VN.7, VN.8, VN.9, VN.10, VN.11, VN.12, VN.13
VBAT_SENSE: C31.P$1, R15.P$1, R16.P$2, U3.31 (PA9)
VSW: L1.2, U1.8 (LX)
VTEMP_FET: C32.P$1, R17.P$2, R18.P$1, U3.25 (PB12)
VTEMP_MOT: C33.P$1, R19.P$1, TEMP.2, U3.30 (PA8)

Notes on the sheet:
PCB rev divider HI / LO r1.1/r1.2 - open / 100k r1.3 - 100k / open



Board: 4 copper layers, 46.0 x 46.0 mm, 192 parts (117 on the bottom side), 100 nets.

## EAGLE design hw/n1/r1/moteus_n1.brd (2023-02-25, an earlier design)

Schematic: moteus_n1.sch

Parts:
A: PAD16AWG_TERM; 16AWG_TERM
AUX1: SM08B-GHS-TB(LF)(SN); JST_SM08B-GHS-TB(LF)(SN); MPN SM08B-GHS-TB(LF)(SN)
AUX2: SM07B-GHS-TB(LF)(SN); JST_SM07B-GHS-TB(LF)(SN); MPN SM07B-GHS-TB(LF)(SN)
B: PAD16AWG_TERM; 16AWG_TERM
C: PAD16AWG_TERM; 16AWG_TERM
C1, C18, C19, C20, C21, C24, C25, C26: DNP; C0402
C2: 1uF 100V; C0805; MPN GCM21BC72A105KE36L
C3, C16, C17, C22, C23: 1uF; C0603; MPN MF-CAP-0603-1uF
C4, C13: 10uF; C1206; MPN MF-CAP-1206-10uF
C5, C10, C34, C36, C37: 1uF; C0402; MPN MF-CAP-0402-1uF
C6: 22uF; C1206; MPN CL31B226KPHNNNE
C7, C8, C9, C11, C12, C14, C15, C28, C29, C38: 0.1uF; C0402; MPN MF-CAP-0402-0.1uF
C27: 0.01uF; C0402; MPN MF-CAP-0402-0.01uF
C30, C31, C32: 1000pF; C0402; MPN MF-CAP-0402-1nF
C33, C35: 0.1uF 100V; C0603; MPN GCJ188R72A104KA01D
C39: 0.47uF 100V; C0805; MPN 08051C474KAT2A
C40, C41, C42: 0.1uF 100V; C1206; MPN 12061C104KAT2A
C43, C44: 100uF 63V; EEHZS1V471UP; MANUFACTURER_PART_NUMBER EEH-ZU1J101V
C45, C46, C47: 4.7uF 100V; C1206; MPN GRJ31CC72A475KE01K
C48, C49, C50, C51, C52, C53, C54, C55, C56, C57, C58, C59, C60: 4.7uF 100V; C1206_NOCREAM_NOBORDER; MPN GRJ31CC72A475KE01K
CAN1, CAN2: JST-PH3; JST_S3B-PH-SM4-TB(LF)(SN); MPN S3B-PH-SM4-TB(LF)(SN)
D1: MF-LED-0603-RED; LED0603
D2: MF-LED-0603-RED; LED0603; MPN MF-LED-0603-GREEN
D3, D4, D5, D6, D7, D8, D9, D10, D11: BAT41KFILM; SODFL1608X70N; MPN BAT41KFILM
D12: DIODE-DO214AA; DO214AA; MPN TPSMB51A-VR
D33, D50: PAD24AWG_PAD; 24AWG_PAD
DAC: PAD24AWG_PAD; 24AWG_PAD
DG1: PAD24AWG_PAD; 24AWG_PAD
DTR: PAD24AWG_PAD; 24AWG_PAD
DTX: PAD24AWG_PAD; 24AWG_PAD
J1, J2: XT30XT30PW_MALE; XT30PW_MALE; MPN XT30PW-M
L1: SRN4018-220M; IND_BOURNS_SRN4018; MANUFACTURER_PART_NUMBER 74404042470
L2: 74404024100; IND_4024100_WRE; MPN 74404024100
M1, M2, M3, M4: MOUNT; M2.5MOUNT
MOT1, MOT2, MOT3: PAD24AWG_PAD; 24AWG_PAD
Q1, Q3, Q5: TPH1R204PL_VIAS; SOP_ADVANCE_8_VIAS; MPN TPH2R408QM,L1Q
Q2, Q4, Q6: TPH1R204PLSOP_ADVANCE_8; SOP_ADVANCE_8; MPN TPH2R408QM,L1Q
R1, R2: DNP; R0402
R3, R15: 100k 1%; R0402; MPN RC0402FR-07100KL
R4, R5, R8, R9, R10, R11, R12, R13, R14: 100; R0402; MPN MF-RES-0402-100
R6, R7, R25, R26: 2k; R0402; MPN MF-RES-0402-2K
R16: 4.7k 1%; R0402; MPN RC0402FR-074K7L
R17: 47k NTC; R0402; MPN NCP15WB473F03RC
R18, R19: 10k 1%; R0402; MPN RC0402FR-0710KL
R20, R21: 560; R0402; MPN MF-RES-0402-560
R22, R23, R24: 22; R0402; MPN MF-RES-0402-22
R27, R28, R30, R31, R32: 7.5; R0402; MPN RC0402FR-077R5L
R29: 7.5; R0805; MPN RC0805FR-077R5L
RA: 0.5mOhm 1% 2W; M1206; MPN HCS1206FTL500
RB: 0.5mOhm 1% 2W; M1206; MPN HCS1206FTL500
RC: 0.5mOhm 1% 2W; M1206; MPN HCS1206FTL500
SH1, SH2, SH3: SHORTT5; SHORT_TOP-50
SH4: SHORTMEDIUM; SHORT_TOP-MEDIUM
SWD: JST-ZH6; JST_S6B-ZR-SM4A-TF(LF)(SN); MPN S6B-ZR-SM4A-TF(LF)(SN)
TEMP1, TEMP2: PAD24AWG_PAD; 24AWG_PAD
U1: MAX15062AATA+T; 21-0487A_MXM; MANUFACTURER_PART_NUMBER MAX15062BATA+T
U2: XC9265A331MR-G; SOT95P280X130-5N; MPN XC9265A331MR-G
U3: STM32G474CEU6; QFN50P700X700X60-49N; MPN STM32G474CEU6
U4: TCAN1042HGV; SOIC8; MPN TCAN1057AEVDRQ1‎
U5: AS5147; TSSOP14; MPN AS5047P-ATSM
U6: CAT25080HU4I-GT3UDFN8_2X3_ONS-M; UDFN8_2X3_ONS-M; MPN CAT24C32HU4I-GT3
U7: DRV8353S; WQFN-40; MPN DRV8353FSRTAR
VN: PAD16AWG_TERM; 16AWG_TERM
VP: PAD16AWG_TERM; 16AWG_TERM

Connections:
+3V3: AUX1.2, AUX2.2, C6.P$1, C7.P$1, C8.P$1, C10.P$1, C11.P$1, C12.P$1, C13.P$2, C15.P$1, C17.P$1, C23.P$1, C38.P$2, D33.P$1, L2.1, R2.P$2, R17.P$1, R20.P$1, R21.P$1, R25.P$1, R26.P$1, SWD.6, TEMP1.P$1, U2.4 (VOUT), U3.1 (VBAT), U3.20 (VREF+), U3.21 (VDDA), U3.23 (VDD_1), U3.35 (VDD_2), U3.48 (VDD_3), U4.5 (VIO), U5.12 (VDD3V), U6.3 (!WP), U6.7 (!HOLD), U6.8 (VCC), U7.24 (VREF)
+5V: AUX1.1, AUX2.1, C4.P$1, C5.P$1, C14.P$1, C16.P$1, C22.P$1, D50.P$1, L1.1, U1.4 (FB/VOUT), U2.1 (VIN), U2.3 (CE), U4.3 (VCC)
AS5047_CS: U3.42 (PB4), U5.1 (CS/)
AS5047_MISO: C26.P$1, R12.P$2, U3.40 (PC11), U5.3 (MISO)
AS5047_MOSI: C25.P$1, R13.P$2, U3.43 (PB5), U5.4 (MOSI)
AS5047_SCK: C24.P$1, R14.P$2, U3.39 (PC10), U5.2 (CLK)
AUX_SC1: C20.P$1, R5.P$2, U3.27 (PB14)
AUX_SC2: C21.P$1, R4.P$2, U3.28 (PB15)
AUX_SCL: C19.P$1, R9.P$2, U3.46 (PB8-BOOT0)
AUX_SDA: C18.P$1, R8.P$2, U3.26 (PB13), U3.47 (PB9)
CAN_N: CAN1.2, CAN2.2, U4.6 (CANL)
CAN_P: CAN1.1, CAN2.1, U4.7 (CANH)
CAN_RX: U3.33 (PA11), U4.4 (RXD)
CAN_TX: U3.34 (PA12), U4.1 (TXD)
CUR1: R22.P$1, U7.23 (SOA)
CUR2: R23.P$1, U7.22 (SOB)
CUR3: R24.P$1, U7.21 (SOC)
DAC: DAC.P$1, R2.P$1, R3.P$2, U3.12 (PA4)
DEBUG_RX: DTR.P$1, U3.45 (PB7)
DEBUG_TX: DTX.P$1, U3.44 (PB6)
DRV8323_CS: U3.17 (PB0), U7.30 (CS)
DRV8323_MISO: R25.P$2, U3.14 (PA6), U6.2 (SO), U7.27 (MISO)
DRV8323_MOSI: U3.15 (PA7), U6.5 (SI), U7.28 (MOSI)
DRV8323_SCLK: U3.13 (PA5), U6.6 (SCK), U7.29 (SCLK)
EEPROM_CS: U3.38 (PA15), U6.1 (!CS)
FCUR1: C30.P$1, R22.P$2, U3.11 (PA3)
FCUR2: C31.P$1, R23.P$2, U3.16 (PC4)
FCUR3: C32.P$1, R24.P$2, U3.18 (PB1)
GHA: D5.1 (K), R28.P$1, U7.6 (GHA)
GHA_D: D5.2 (A), Q1.4 (G), R28.P$2
GHB: D8.1 (K), R30.P$1, U7.15 (GHB)
GHB_D: D8.2 (A), Q3.4 (G), R30.P$2
GHC: D11.1 (K), R32.P$1, U7.16 (GHC)
GHC_D: D11.2 (A), Q5.4 (G), R32.P$2
GLA: D3.1 (K), R27.P$1, U7.8 (GLA)
GLA_D: D3.2 (A), D4.1 (K), Q2.4 (G), R27.P$2
GLB: D6.1 (K), R29.P$1, U7.13 (GLB)
GLB_D: D6.2 (A), D7.1 (K), Q4.4 (G), R29.P$2
GLC: D9.1 (K), R31.P$1, U7.18 (GLC)
GLC_D: D9.2 (A), D10.1 (K), Q6.4 (G), R31.P$2
GND: AUX1.8, AUX2.7, C3.P$2, C4.P$2, C5.P$2, C6.P$2, C7.P$2, C8.P$2, C9.P$2, C10.P$2, C11.P$2, C12.P$2, C13.P$1, C14.P$2, C15.P$2, C16.P$2, C17.P$2, C18.P$2, C19.P$2, C20.P$2, C21.P$2, C22.P$2, C23.P$2, C24.P$2, C25.P$2, C26.P$2, C27.P$2, C28.P$2, C29.P$2, C30.P$2, C31.P$2, C32.P$2, C38.P$1, CAN1.3, CAN2.3, DG1.P$1, R3.P$1, R16.P$1, R18.P$2, R19.P$2, SH4.2, SWD.4, U1.7 (GND), U2.2 (GND), U3.49 (THERMALPAD), U4.2 (GND), U4.8 (STB), U5.5 (TEST), U5.13 (GND), U6.4 (VSS), U7.25 (AGND)
I2C_PULLUP: R6.P$1, R7.P$1, U3.41 (PB3)
LED1: D1.CATHODE, U3.5 (PF0-OSC_IN)
LED2: D2.CATHODE, U3.6 (PF1-OSC_OUT)
MOTOR1: MOT1.P$1, U3.8 (PA0), U7.32 (INHA)
MOTOR2: MOT2.P$1, U3.9 (PA1), U7.34 (INHB)
MOTOR3: MOT3.P$1, U3.10 (PA2), U7.36 (INHC)
MOTOR_ENABLE: U3.3 (PC14-OSC32_IN), U7.31 (ENABLE)
MOTOR_FAULT: R26.P$2, U3.2 (PC13), U7.26 (FAULT)
MOTOR_HIZ: U3.4 (PC15-OSC32_OUT), U7.33 (INLA), U7.35 (INLB), U7.37 (INLC)
unnamed: C1.P$1, M3.P$1, R1.P$1
unnamed: C36.P$2, U7.40 (VGLS)
unnamed: AUX2.3, R4.P$1
unnamed: C3.P$1, U1.3 (VCC)
unnamed: L2.2, U2.5 (LX)
unnamed: AUX2.4, R5.P$1
unnamed: AUX2.6, R6.P$2, R8.P$1
unnamed: AUX2.5, R7.P$2, R9.P$1
unnamed: AUX1.3, R10.P$1
unnamed: C35.P$2, U7.1 (CPL)
unnamed: AUX1.4, R11.P$1
unnamed: AUX1.5, R12.P$1
unnamed: C35.P$1, U7.2 (CPH)
unnamed: C34.P$2, U7.5 (VCP)
unnamed: AUX1.6, R13.P$1
unnamed: C37.P$2, U7.38 (DVDD)
unnamed: D1.ANODE, R20.P$2
unnamed: D2.ANODE, R21.P$2
unnamed: AUX1.7, R14.P$1
NRST: C9.P$1, SWD.2, U3.7 (PG10-NRST)
PRIMARY_CS: R11.P$2, U3.19 (PB2)
PRIMARY_EXTRA: R10.P$2, U3.24 (PB11)
S1: AUX2.S1
S2: AUX2.S2
SHA: A.1, A.2, A.3, A.4, A.5, A.6, A.7, A.8, A.9, A.10, A.11, A.12, Q1.1 (S), Q1.2 (S), Q1.3 (S), Q2.5 (D), Q2.6 (D), Q2.7 (D), Q2.8 (D), Q2.PAD (D), U7.7 (SHA)
SHB: B.1, B.2, B.3, B.4, B.5, B.6, B.7, B.8, B.9, B.10, B.11, B.12, Q3.1 (S), Q3.2 (S), Q3.3 (S), Q4.5 (D), Q4.6 (D), Q4.7 (D), Q4.8 (D), Q4.PAD (D), U7.14 (SHB)
SHC: C.1, C.2, C.3, C.4, C.5, C.6, C.7, C.8, C.9, C.10, C.11, C.12, Q5.1 (S), Q5.2 (S), Q5.3 (S), Q6.5 (D), Q6.6 (D), Q6.7 (D), Q6.8 (D), Q6.PAD (D), U7.17 (SHC)
SWCLK: SWD.5, U3.37 (PA14)
SWDIO: SWD.3, U3.36 (PA13)
SXA_N: SH1.1, U7.10 (SNA)
SXA_P: C40.P$2, Q2.1 (S), Q2.2 (S), Q2.3 (S), RA.2, U7.9 (SPA)
SXB_N: SH2.1, U7.11 (SNB)
SXB_P: C41.P$2, Q4.1 (S), Q4.2 (S), Q4.3 (S), RB.2, U7.12 (SPB)
SXC_N: SH3.1, U7.20 (SNC)
SXC_P: C42.P$2, Q6.1 (S), Q6.2 (S), Q6.3 (S), RC.2, U7.19 (SPC)
V+: C2.P$1, C33.P$1, C34.P$1, C39.P$1, C40.P$1, C41.P$1, C42.P$1, C43.1 (+), C44.1 (+), C45.P$1, C46.P$1, C47.P$1, C48.P$1, C49.P$1, C50.P$1, C51.P$1, C52.P$1, C53.P$1, C54.P$1, C55.P$1, C56.P$1, C57.P$1, C58.P$1, C59.P$1, C60.P$1, D12.C, J1.1, J2.1, Q1.5 (D), Q1.6 (D), Q1.7 (D), Q1.8 (D), Q1.PAD (D), Q3.5 (D), Q3.6 (D), Q3.7 (D), Q3.8 (D), Q3.PAD (D), Q5.5 (D), Q5.6 (D), Q5.7 (D), Q5.8 (D), Q5.PAD (D), R15.P$2, U1.1 (VIN), U1.2 (EN/UVLO), U7.3 (VM), U7.4 (VDRAIN), VP.1, VP.2, VP.3, VP.4, VP.5, VP.6, VP.7, VP.8, VP.9, VP.10, VP.11, VP.12
V-: C1.P$2, C2.P$2, C33.P$2, C36.P$1, C37.P$1, C39.P$2, C43.2 (-), C44.2 (-), C45.P$2, C46.P$2, C47.P$2, C48.P$2, C49.P$2, C50.P$2, C51.P$2, C52.P$2, C53.P$2, C54.P$2, C55.P$2, C56.P$2, C57.P$2, C58.P$2, C59.P$2, C60.P$2, D4.2 (A), D7.2 (A), D10.2 (A), D12.A, J1.2, J2.2, R1.P$2, RA.1, RB.1, RC.1, SH1.2, SH2.2, SH3.2, SH4.1, U7.39 (GND), U7.P1 (PAD), U7.P2 (PAD), U7.P3 (PAD), U7.P7 (PAD), U7.P8 (PAD), U7.P9 (PAD), U7.P12 (PAD), U7.P13 (PAD), U7.P14 (PAD), U7.P17 (PAD), U7.P18 (PAD), U7.P19 (PAD), U7.PAD, VN.1, VN.2, VN.3, VN.4, VN.5, VN.6, VN.7, VN.8, VN.9, VN.10, VN.11, VN.12
VBAT_SENSE: C27.P$1, R15.P$1, R16.P$2, U3.31 (PA9)
VSW: L1.2, U1.8 (LX)
VTEMP_FET: C28.P$1, R17.P$2, R18.P$1, U3.25 (PB12)
VTEMP_MOT: C29.P$1, R19.P$1, TEMP2.P$1, U3.30 (PA8)

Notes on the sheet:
PCB rev divider HI / LO r1 - open / 100k



Board: 4 copper layers, 46.0 x 46.0 mm, 153 parts (82 on the bottom side), 89 nets.

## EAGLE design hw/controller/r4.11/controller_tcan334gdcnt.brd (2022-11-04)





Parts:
A: PAD16AWG_PAD; 16AWG_PAD
ABS: JST_ZH4; JST_S4B-ZR-SM4A-TF(LF)(SN); MPN S4B-ZR-SM4A-TF(LF)(SN)
B: PAD16AWG_PAD; 16AWG_PAD
C: PAD16AWG_PAD; 16AWG_PAD
C1, C2, C3, C5, C6, C8, C10, C12, C13, C18: 0.1uF; C0402; MPN MF-CAP-0402-0.1uF
C4, C9, C15, C17, C56: 1uF; C0402; MPN MF-CAP-0402-1uF
C7, C21: 10uF; C1206; MPN MF-CAP-1206-10uF
C11: 0.1uF; C0402_NOBORDER; MPN MF-CAP-0402-0.1uF
C14, C16: 0.1uF 50V; C0402; MPN CGA2B3X7R1H104K050BB
C19: 0.47uF 50V; C0402; MPN GRM155R61H474KE11D
C20: 1uF; C0603; MPN MF-CAP-0603-1uF
C22, C23, C24, C25, C26, C27, C28, C29, C30, C31, C32, C33, C34, C36, C37: 10uF 50V; C1206; MPN C3216X7R1H106K160AE
C35: 10uF 50V; C1206_NOBORDER; MPN C3216X7R1H106K160AE
C38: 1uF; C0603; MPN C1608X7R1E105K080AE
C39: 1uF 100V; C0805; MPN GCM21BC72A105KE36L
C40, C41, C42, C43, C44, C45, C46, C47, C48, C49, C50, C51, C52, C53, C54: DNP; C1206_NOCREAM
C55: DNP; C0402
C57: 0.01uF; C0402; MPN MF-CAP-0402-0.01uF
C58, C59, C60: 1000pF; C0402_NOBORDER; MPN MF-CAP-0402-1nF
C61, C63: 0.1uF 50V; C1206; MPN 12065C104KAZ2A
C62: 0.1uF 50V; C0603_NOBORDER; MPN 06035C104KAZ2A
CAN1, CAN2: JST-PH3; JST_S3B-PH-SM4-TB(LF)(SN); MPN S3B-PH-SM4-TB(LF)(SN)
D1, D5, D6, D7, D8, D9, D10, D11, D12: BAT41KFILM; SODFL1608X70N; MPN BAT41KFILM
D2: MF-LED-0603-RED; LED0603; MPN MF-LED-0603-GREEN
D3: MF-LED-0603-RED; LED0603
D4: DUAL_TVS; SOT23-3; MPN CDSOT23-0502B
D33: PAD24AWG_PAD; 24AWG_PAD
DA: PAD24AWG_PAD; 24AWG_PAD
DAC: PAD24AWG_PAD; 24AWG_PAD
DB: PAD24AWG_PAD; 24AWG_PAD
DBG1, DBG2: PAD24AWG_PAD; 24AWG_PAD
DC: PAD24AWG_PAD; 24AWG_PAD
DG1, DG2: PAD24AWG_PAD; 24AWG_PAD
DRV_CS: PAD24AWG_PAD; 24AWG_PAD
DRV_MISO: PAD24AWG_PAD; 24AWG_PAD
DRV_MOSI: PAD24AWG_PAD; 24AWG_PAD
DRV_SCK: PAD24AWG_PAD; 24AWG_PAD
DTR: PAD24AWG_PAD; 24AWG_PAD
DTX: PAD24AWG_PAD; 24AWG_PAD
ENC: PICO-SPOX-6NOPASTE; PICO-SPOX-SMT-RA-6-NOPASTE
J1, J2: XT30XT30PW_MALE; XT30PW_MALE
L1: SRN4018-220M; IND_BOURNS_SRN4018; MANUFACTURER_PART_NUMBER SRN4018-330M
L2, L3: HALF_CHOKE; 1812_COMMON_HALF; MPN MF-RES-0805-0
M1, M2, M3, M4: MOUNT; M2.5MOUNT
MOT1, MOT2, MOT3: PAD24AWG_PAD; 24AWG_PAD
Q1, Q2, Q3, Q4, Q5, Q6: TPH1R204PLSOP_ADVANCE_8; SOP_ADVANCE_8; MPN TPH2R506PL,L1Q
R1, R2: 560; R0402; MPN MF-RES-0402-560
R3, R4, R13, R14: 2k; R0402; MPN MF-RES-0402-2K
R5: 100k 1%; R0402; MPN RC0402FR-07100KL
R6: 4.7k 1%; R0402; MPN RC0402FR-074K7L
R7, R9: 10k 1%; R0402; MPN RC0402FR-0710KL
R8: 47k NTC; R0402; MPN NCP15WB473F03RC
R10: DNP; R0402
R15, R16, R17: 22; R0402_NOBORDER; MPN MF-RES-0402-22
R22, R23, R24, R25, R26, R27: 7.5; R0402; MPN RC0402FR-077R5L
RA: 0.5mOhm 1% 2W; M1206; MPN HCS1206FTL500
RB: 0.5mOhm 1% 2W; M1206; MPN HCS1206FTL500
RC: 0.5mOhm 1% 2W; M1206; MPN HCS1206FTL500
SH1, SH2, SH3: SHORTT5; SHORT_TOP-50
SH4: SHORTMEDIUM; SHORT_TOP-MEDIUM
SWD: JST-ZH6; JST_S6B-ZR-SM4A-TF(LF)(SN); MPN S6B-ZR-SM4A-TF(LF)(SN)
TEMP1, TEMP2: PAD24AWG_PAD; 24AWG_PAD
U1: STM32G474CEU6; QFN50P700X700X60-49N; MPN STM32G474CEU6
U2: TCAN334G; SOIC8; MPN TCAN337GDR
U3: AS5147; TSSOP14; MPN AS5047P-ATSM
U4: MAX15062AATA+T; 21-0487A_MXM; MPN MAX15062AATA+T
U5: DRV8353S; WQFN-40; MPN DRV8353FSRTAR
U6: TCAN334GSOT23; SOT23-8; MPN TCAN334GDCNT

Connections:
+3V3: ABS.1, C1.P$1, C2.P$1, C4.P$1, C5.P$1, C6.P$1, C7.P$2, C8.P$1, C9.P$1, C10.P$1, C11.P$1, C12.P$1, C18.P$2, C21.P$1, C56.P$1, D33.P$1, ENC.1, L1.1, R1.P$1, R2.P$1, R3.P$1, R4.P$1, R8.P$1, R13.P$1, R14.P$1, SWD.6, TEMP1.P$1, U1.1 (VBAT), U1.20 (VREF+), U1.21 (VDDA), U1.23 (VDD_1), U1.35 (VDD_2), U1.48 (VDD_3), U2.3 (VCC), U3.12 (VDD3V), U4.4 (FB/VOUT), U5.24 (VREF), U6.3 (VCC)
AS5047_A: U1.43 (PB5), U3.7 (A)
AS5047_B: U1.42 (PB4), U3.6 (B)
AS5047_CS: U1.24 (PB11), U3.1 (CS/)
AS5047_MISO: ENC.5, U1.27 (PB14), U3.3 (MISO)
AS5047_MOSI: ENC.6, U1.28 (PB15), U3.4 (MOSI)
AS5047_SCK: ENC.4, U1.26 (PB13), U3.2 (CLK)
CAN2_N: L2.P$2 (2), U2.6 (CANL), U6.6 (CANL)
CAN2_P: L3.P$2 (2), U2.7 (CANH), U6.7 (CANH)
CAN_N: CAN1.2, CAN2.2, D4.2, L2.P$1 (1)
CAN_P: CAN1.1, CAN2.1, D4.1, L3.P$1 (1)
CAN_RX: U1.33 (PA11), U2.4 (RXD), U6.4 (RXD)
CAN_TX: U1.34 (PA12), U2.1 (TXD), U6.1 (TXD)
CUR1: R15.P$1, U5.23 (SOA)
CUR2: R16.P$1, U5.22 (SOB)
CUR3: R17.P$1, U5.21 (SOC)
DAC: DAC.P$1, U1.12 (PA4)
DEBUG1: DBG1.P$1, U1.3 (PC14-OSC32_IN)
DEBUG2: DBG2.P$1, U1.4 (PC15-OSC32_OUT)
DEBUG_RX: DTR.P$1, U1.40 (PC11)
DEBUG_TX: DTX.P$1, U1.39 (PC10)
DRV8323_CS: DRV_CS.P$1, U1.16 (PC4), U5.30 (CS)
DRV8323_MISO: DRV_MISO.P$1, R13.P$2, U1.14 (PA6), U5.27 (MISO)
DRV8323_MOSI: DRV_MOSI.P$1, U1.15 (PA7), U5.28 (MOSI)
DRV8323_SCLK: DRV_SCK.P$1, U1.13 (PA5), U5.29 (SCLK)
FCUR1: C58.P$1, R15.P$2, U1.17 (PB0)
FCUR2: C59.P$1, R16.P$2, U1.18 (PB1)
FCUR3: C60.P$1, R17.P$2, U1.19 (PB2)
GHA: D10.1 (K), R22.P$1, U5.6 (GHA)
GHA_D: D10.2 (A), Q1.4 (G), R22.P$2
GHB: D11.1 (K), R24.P$1, U5.15 (GHB)
GHB_D: D11.2 (A), Q3.4 (G), R24.P$2
GHC: D12.1 (K), R26.P$1, U5.16 (GHC)
GHC_D: D12.2 (A), Q5.4 (G), R26.P$2
GLA: D7.1 (K), R23.P$1, U5.8 (GLA)
GLA_D: D1.1 (K), D7.2 (A), Q2.4 (G), R23.P$2
GLB: D8.1 (K), R25.P$1, U5.13 (GLB)
GLB_D: D5.1 (K), D8.2 (A), Q4.4 (G), R25.P$2
GLC: D9.1 (K), R27.P$1, U5.18 (GLC)
GLC_D: D6.1 (K), D9.2 (A), Q6.4 (G), R27.P$2
GND: ABS.4, C1.P$2, C2.P$2, C3.P$2, C4.P$2, C5.P$2, C6.P$2, C7.P$1, C8.P$2, C9.P$2, C10.P$2, C11.P$2, C12.P$2, C13.P$2, C18.P$1, C20.P$2, C21.P$2, C56.P$2, C57.P$2, C58.P$2, C59.P$2, C60.P$2, CAN1.3, CAN2.3, D4.3, DG1.P$1, DG2.P$1, ENC.3, R6.P$1, R7.P$2, R9.P$2, SH4.2, SWD.4, U1.32 (PA10), U1.49 (THERMALPAD), U2.2 (GND), U2.5 (SHDN), U2.8 (STB), U3.5 (TEST), U3.13 (GND), U4.7 (GND), U5.25 (AGND), U6.2 (GND), U6.5 (SHDN), U6.8 (STB)
I2C_ABS_SCL: ABS.2, R4.P$2, U1.46 (PB8-BOOT0)
I2C_ABS_SDA: ABS.3, R3.P$2, U1.47 (PB9)
LED1: D3.CATHODE, U1.5 (PF0-OSC_IN)
LED2: D2.CATHODE, U1.6 (PF1-OSC_OUT)
MOTOR1: MOT1.P$1, U1.8 (PA0), U5.32 (INHA)
MOTOR2: MOT2.P$1, U1.9 (PA1), U5.34 (INHB)
MOTOR3: MOT3.P$1, U1.10 (PA2), U5.36 (INHC)
MOTOR_ENABLE: U1.11 (PA3), U5.31 (ENABLE)
MOTOR_FAULT: R14.P$2, U1.44 (PB6), U5.26 (FAULT)
MOTOR_HIZ: U1.45 (PB7), U5.33 (INLA), U5.35 (INLB), U5.37 (INLC)
unnamed: C55.P$1, M3.P$1, R10.P$1
unnamed: C38.P$2, U5.40 (VGLS)
unnamed: C20.P$1, U4.3 (VCC)
unnamed: C16.P$2, U5.1 (CPL)
unnamed: C16.P$1, U5.2 (CPH)
unnamed: C15.P$2, U5.5 (VCP)
unnamed: C17.P$2, U5.38 (DVDD)
unnamed: D3.ANODE, R1.P$2
unnamed: D2.ANODE, R2.P$2
NRST: C3.P$1, SWD.2, U1.7 (PG10-NRST)
SECONDARY_ENC_CS: ENC.2, U1.2 (PC13)
SHA: A.1, DA.P$1, Q1.1 (S), Q1.2 (S), Q1.3 (S), Q2.5 (D), Q2.6 (D), Q2.7 (D), Q2.8 (D), Q2.PAD (D), U5.7 (SHA)
SHB: B.1, DB.P$1, Q3.1 (S), Q3.2 (S), Q3.3 (S), Q4.5 (D), Q4.6 (D), Q4.7 (D), Q4.8 (D), Q4.PAD (D), U5.14 (SHB)
SHC: C.1, DC.P$1, Q5.1 (S), Q5.2 (S), Q5.3 (S), Q6.5 (D), Q6.6 (D), Q6.7 (D), Q6.8 (D), Q6.PAD (D), U5.17 (SHC)
SWCLK: SWD.5, U1.37 (PA14)
SWDIO: SWD.3, U1.36 (PA13)
SXA_N: SH1.1, U5.10 (SNA)
SXA_P: C61.P$2, Q2.1 (S), Q2.2 (S), Q2.3 (S), RA.2, U5.9 (SPA)
SXB_N: SH2.1, U5.11 (SNB)
SXB_P: C62.P$2, Q4.1 (S), Q4.2 (S), Q4.3 (S), RB.2, U5.12 (SPB)
SXC_N: SH3.1, U5.20 (SNC)
SXC_P: C63.P$2, Q6.1 (S), Q6.2 (S), Q6.3 (S), RC.2, U5.19 (SPC)
V+: C14.P$1, C15.P$1, C19.P$1, C22.P$1, C23.P$1, C24.P$1, C25.P$1, C26.P$1, C27.P$1, C28.P$1, C29.P$1, C30.P$1, C31.P$1, C32.P$1, C33.P$1, C34.P$1, C35.P$1, C36.P$1, C37.P$1, C39.P$1, C40.P$1, C41.P$1, C42.P$1, C43.P$1, C44.P$1, C45.P$1, C46.P$1, C47.P$1, C48.P$1, C49.P$1, C50.P$1, C51.P$1, C52.P$1, C53.P$1, C54.P$1, C61.P$1, C62.P$1, C63.P$1, J1.1, J2.1, Q1.5 (D), Q1.6 (D), Q1.7 (D), Q1.8 (D), Q1.PAD (D), Q3.5 (D), Q3.6 (D), Q3.7 (D), Q3.8 (D), Q3.PAD (D), Q5.5 (D), Q5.6 (D), Q5.7 (D), Q5.8 (D), Q5.PAD (D), R5.P$2, U4.1 (VIN), U4.2 (EN/UVLO), U5.3 (VM), U5.4 (VDRAIN)
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

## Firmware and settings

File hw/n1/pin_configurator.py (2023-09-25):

#!/usr/bin/python3

# Copyright 2023 mjbots Robotic Systems, LLC.  info@mjbots.com
#
# Licensed under the Apache License, Version 2.0 (the "License");
# you may not use this file except in compliance with the License.
# You may obtain a copy of the License at
#
#     http://www.apache.org/licenses/LICENSE-2.0
#
# Unless required by applicable law or agreed to in writing, software
# distributed under the License is distributed on an "AS IS" BASIS,
# WITHOUT WARRANTIES OR CONDITIONS OF ANY KIND, either express or implied.
# See the License for the specific language governing permissions and
# limitations under the License.

import argparse
import enum
import re
import sys


class MatchStatus(enum.IntEnum):
    VALID = 1
    INCONCLUSIVE = 0
    IMPOSSIBLE = -1


def generic_search(data, to_find):
    found = [d.find(to_find) >= 0 for d in data]
    if any(found):
        return found.index(True)
    return None

def find_and_remove(data, to_find, compare=generic_search):
    hit = compare(data, to_find)
    if hit is not None:
        del(data[hit])
        return 1
    return 0


class Desired5V:
    def __init__(self, args):
        self.args = args

    def __call__(self, pins):
        for pin in pins:
            for subpin in pin.split('/'):
                if subpin.find('5V') < 0:
                    return MatchStatus.IMPOSSIBLE
        if len(pins) == self.args.pins:
            return MatchStatus.VALID
        return MatchStatus.INCONCLUSIVE


class DesiredADC:
    def __init__(self, args):
        self.args = args
        self.available_adcs = [
            x for x in ['ADC1', 'ADC2', 'ADC3', 'ADC4']
            if x not in self.args.exclude
        ]

    def all_analog(self, maybe_pair):
        pins = maybe_pair.split('/')
        return all([x.find('ANALOG') >= 0 for x in pins])

    def find_adc(self, data, to_find):
        found = [d.find(to_find) >= 0 and self.all_analog(d) for d in data]
        if any(found):
            return found.index(True)
        return None

    def __call__(self, pins):
        # This is not strictly correct, as it will count multiple
        # channels on the same pin as multiple ADCs.  We'll fix that
        # in an ad-hoc way if it matters.

        adc_present = []
        pins_copy = pins[:]
        for adc in self.available_adcs:
            adc_present.append(find_and_remove(pins_copy, adc,
                                               compare=self.find_adc))

        count = sum(adc_present)
        if count == 2:
            return MatchStatus.VALID
        elif (2 - count) + len(pins) > self.args.pins:
            return MatchStatus.IMPOSSIBLE
        else:
            return MatchStatus.INCONCLUSIVE


class DesiredUART:
    def __init__(self, args):
        self.args = args
        self.available_uarts = [
            x for x in ['USART1', 'USART2', 'USART3', 'UART4', 'UART5', 'LPUART1']
            if x not in self.args.exclude
        ]

    def __call__(self, pins):

        results = []
        for uart in self.available_uarts:
            pins_copy = pins[:]
            tx = find_and_remove(pins_copy, f'{uart}_TX')
            rx = find_and_remove(pins_copy, f'{uart}_RX')

            if tx > 0 and rx > 0:
                return MatchStatus.VALID
            elif (2 - tx - rx) + len(pins) > self.args.pins:
                results.append(MatchStatus.IMPOSSIBLE)
            else:
                results.append(MatchStatus.INCONCLUSIVE)
        return max(results)


class DesiredI2C:
    def __init__(self, args):
        self.args = args
        self.available_i2c = [
            x for x in ['I2C1', 'I2C2', 'I2C3', 'I2C4', 'I2C5']
            if x not in self.args.exclude
        ]

    def __call__(self, pins):
        results = []
        for i2c in self.available_i2c:
            pins_copy = pins[:]
            sda = find_and_remove(pins_copy, f'{i2c}_SDA')
            scl = find_and_remove(pins_copy, f'{i2c}_SCL')

            if sda > 0 and scl > 0:
                return MatchStatus.VALID
            elif (2 - sda - scl) + len(pins) > self.args.pins:
                results.append(MatchStatus.IMPOSSIBLE)
            else:
                results.append(MatchStatus.INCONCLUSIVE)

        return max(results)


class DesiredQuadrature:
    def __init__(self, args):
        self.args = args
        self.available_timers = [
            x for x in ['TIM1', 'TIM2', 'TIM3', 'TIM4', 'TIM5', 'TIM8', 'TIM20']
            if x not in self.args.exclude
        ]

    def __call__(self, pins):
        results = []

        for timer in self.available_timers:
            pins_copy = pins[:]
            ch1 = find_and_remove(pins_copy, f'{timer}_CH1')
            ch2 = find_and_remove(pins_copy, f'{timer}_CH2')

            if ch1 > 0 and ch2 > 0:
                return MatchStatus.VALID
            elif (2 - ch1 - ch1) + len(pins) > self.args.pins:
                results.append(MatchStatus.IMPOSSIBLE)
            else:
                results.append(MatchStatus.INCONCLUSIVE)
        return max(results)


class DesiredSpi:
    def __init__(self, args):
        self.args = args
        self.available_spi = [
            x for x in ['SPI1', 'SPI2', 'SPI3', 'SPI4', 'SPI5']
            if x not in self.args.exclude
        ]

    def any_non_five_volt(self, pins_copy):
        for pin_pair in pins_copy:
            for pin in pin_pair.split('/'):
                if pin.find('5V') < 0:
                    return True
        return False

    def __call__(self, pins):
        results = []

        # Just check all 5 SPI types.
        for spi in self.available_spi:
            sck = 0
            miso = 0
            mosi = 0

            pins_copy = pins[:]

            sck = find_and_remove(pins_copy, f'{spi}_SCK')
            miso = find_and_remove(pins_copy, f'{spi}_MISO')
            mosi = find_and_remove(pins_copy, f'{spi}_MOSI')

            if self.args.nonspi_five_volt:
                # All remaining pins must be 5V.
                if self.any_non_five_volt(pins_copy):
                    results.append(MatchStatus.IMPOSSIBLE)
                    continue


            if sck > 0 and miso > 0 and mosi > 0:
                return MatchStatus.VALID
            elif (3 - sck - miso - mosi) + len(pins) > self.args.pins:
                results.append(MatchStatus.IMPOSSIBLE)
            else:
                results.append(MatchStatus.INCONCLUSIVE)
        return max(results)

    def find_nonspi(self, pins):
        results = []

        # Just check all 5 SPI types.
        for spi in self.available_spi:
            sck = 0
            miso = 0
            mosi = 0

            pins_copy = pins[:]

            sck = find_and_remove(pins_copy, f'{spi}_SCK')
            miso = find_and_remove(pins_copy, f'{spi}_MISO')
            mosi = find_and_remove(pins_copy, f'{spi}_MOSI')

            if sck > 0 and miso > 0 and mosi > 0:
                return pins_copy
        return None


def main():
    parser = argparse.ArgumentParser()
    parser.add_argument('--pins', type=int, default=5)
    parser.add_argument('--pinout', default='pinout.txt')
    parser.add_argument('--five-volt', action='store_true')
    parser.add_argument('--verbose', '-v', action='store_true')
    parser.add_argument('--exclude', '-e', action='append', default=[])
    parser.add_argument('--nonspi-five-volt', action='store_true')
    parser.add_argument('--max-doubled', default=10, type=int)

    parser.add_argument('--action', '-a', default='search', type=str)

    parser.add_argument('--verify', '-f', type=str)

    args = parser.parse_args()

    lines = [x.strip() for x in open(args.pinout).readlines()
             if (not x.startswith('#') and
                 x.split(' ')[0] not in args.exclude)]

    if args.action == 'search':
        do_search(args, lines)
    if args.action == 'verify':
        do_verify(args, lines)

def do_verify(args, lines):
    def get_pin(pin):
        return [x for x in lines if x.startswith(pin + ' ')][0]

    pins = []
    pin_pairs = args.verify.split(',')
    for pair in pin_pairs:
        pins.append(' / '.join([get_pin(pin) for pin in pair.split('/')]))

    to_check = [
        ('SPI', DesiredSpi(args)),
        ('QUAD', DesiredQuadrature(args)),
        ('I2C', DesiredI2C(args)),
        ('UART', DesiredUART(args)),
        ('ADC', DesiredADC(args)),
    ]

    for check in to_check:
        print(f"{check[0]} - {check[1](pins)}")

    desired_spi = DesiredSpi(args)
    nonspi_desired = [
        DesiredQuadrature(args),
        DesiredI2C(args),
        DesiredUART(args),
        DesiredADC(args),
    ]

    nonspi_pins = desired_spi.find_nonspi(pins)
    bonus = [d(nonspi_pins)
             for d in nonspi_desired].count(MatchStatus.VALID) * 2

    print(f"bonus {bonus}")



def do_search(args, lines):
    desired_spi = DesiredSpi(args)

    nonspi_desired = [
        DesiredQuadrature(args),
        DesiredI2C(args),
        DesiredUART(args),
        DesiredADC(args),
    ]

    desired = [ desired_spi ] + nonspi_desired

    if args.five_volt:
        desired.append(Desired5V(args))

    current = [0]
    tries = 0

    best_score = 1000
    best_doubled = 1000

    while True:
        tries += 1
        these_pins_doubled = [lines[x] for x in current]
        short_doubled = [x.split(' ')[0] for x in these_pins_doubled]
        these_pins = []
        while len(these_pins_doubled):
            maybe_pair = these_pins_doubled[0:2]

            if len(maybe_pair) == 1 or maybe_pair[0] == maybe_pair[1]:
                these_pins.append(maybe_pair[0])
            else:
                these_pins.append(' / '.join(maybe_pair))
            del(these_pins_doubled[0:2])

        #print(f"TRYING: {these_pins}")
        these_pins_short = []
        while len(short_doubled):
            short_pair = short_doubled[0:2]
            if len(short_pair) == 2 and short_pair[0] == short_pair[1]:
                del(short_pair[1])
            these_pins_short.append('/'.join(short_pair))
            del(short_doubled[0:2])

        doubled = ','.join(these_pins_short).count('/')

        print(f"{tries}   {','.join(these_pins_short)}     ",
              end='\n' if args.verbose else '\r')

        if tries == 116803:
            a = 1

        if doubled <= args.max_doubled:
            results = [d(these_pins) for d in desired]
        else:
            results = [MatchStatus.IMPOSSIBLE]

        b = 1

        if all([x == MatchStatus.VALID for x in results]):
            pin_count = len(current)
            nonspi_pins = desired_spi.find_nonspi(these_pins)
            bonus = [d(nonspi_pins)
                     for d in nonspi_desired].count(MatchStatus.VALID) * 2
            score = pin_count + doubled * 2 - bonus
            if doubled < best_doubled:
                best_doubled = doubled
            if score <= best_score:
                best_score = score
                print()
                print()
                print(f"FOUND after {tries} tries w/ {pin_count} pins {doubled} doubled {score} score - {bonus} bonus")
                print('\n'.join(these_pins))
                print()

        if (any([x == MatchStatus.IMPOSSIBLE for x in results]) or
              len(current) >= args.pins * 2 or
              (current[-1] + 1) >= len(lines)):
            # We need to advance the current index.  If that exceeds
            # our limit, then backtrack if possible.
            while True:
                current[-1] += 1
                if len(current) >=2 and current[-1] == current[-2]:
                    continue
                if current[-1] < len(lines):
                    break
                current.pop()
                if len(current) == 0:
                    print("IMPOSSIBLE")
                    sys.exit(1)
        else:
            if len(current) % 2 == 0:
                current.append(current[-2] + 1)
            else:
                current.append(current[-1])



if __name__ == '__main__':
    main()

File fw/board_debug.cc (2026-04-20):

// Copyright 2023 mjbots Robotic Systems, LLC.  info@mjbots.com
//
// Licensed under the Apache License, Version 2.0 (the "License");
// you may not use this file except in compliance with the License.
// You may obtain a copy of the License at
//
//     http://www.apache.org/licenses/LICENSE-2.0
//
// Unless required by applicable law or agreed to in writing, software
// distributed under the License is distributed on an "AS IS" BASIS,
// WITHOUT WARRANTIES OR CONDITIONS OF ANY KIND, either express or implied.
// See the License for the specific language governing permissions and
// limitations under the License.

#include "fw/board_debug.h"

#include <cctype>
#include <cstdlib>
#include <functional>
#include <numeric>

#include "mbed.h"

#include "mjlib/base/inplace_function.h"
#include "mjlib/base/tokenizer.h"
#include "mjlib/base/visitor.h"

#include "fw/as5047.h"
#include "fw/bldc_servo.h"
#include "fw/bootloader.h"
#include "fw/drv8323.h"
#include "fw/moteus_hw.h"
#include "fw/strtof.h"

namespace base = mjlib::base;
namespace micro = mjlib::micro;
namespace multiplex = mjlib::multiplex;

namespace moteus {
constexpr float kCalibrationStep = 0.002;
constexpr float kMaxCalPoleCount = 50.0f;

namespace {
void recurse(int count, base::inplace_function<void(int)> callback) {
  callback(count - 1);
}

bool ParseOptions(BldcServo::CommandData* command, base::Tokenizer* tokenizer,
                  const char* valid_options) {
  while (tokenizer->remaining().size()) {
    const auto token = tokenizer->next();
    // We accept optional arguments, each prefixed by a single
    // character.
    if (token.size() < 1) { continue; }
    const char option = token[0];
    if (::strchr(valid_options, option) == nullptr) {
      return false;
    }

    const auto maybe_value = Strtof(&token[1]);
    if (!maybe_value) {
      return false;
    }
    const auto value = *maybe_value;
    switch (option) {
      case 'p': {
        command->kp_scale = value;
        break;
      }
      case 'd': {
        command->kd_scale = value;
        break;
      }
      case 'i': {
        command->ilimit_scale = value;
        break;
      }
      case 's': {
        command->stop_position = value;
        break;
      }
      case 'f': {
        command->feedforward_Nm = value;
        break;
      }
      case 't': {
        command->timeout_s = value;
        break;
      }
      case 'a': {
        command->accel_limit = value;
        break;
      }
      case 'v': {
        command->velocity_limit = value;
        break;
      }
      case 'o': {
        command->fixed_voltage_override = value;
        break;
      }
      case 'c': {
        command->fixed_current_override = value;
        break;
      }
      case 'b': {
        command->ignore_position_bounds = value != 0.0f;
        break;
      }
      case 'q': {
        command->meas_ind_axis = static_cast<int8_t>(value);
        break;
      }
      default: {
        return false;
      }
    }
  }
  return true;
}
}

class BoardDebug::Impl {
 public:
  struct HistogramSource;

  Impl(micro::Pool* pool,
       micro::CommandManager* command_manager,
       micro::TelemetryManager* telemetry_manager,
       multiplex::MicroServer* multiplex_protocol,
       BldcServo* bldc_servo)
      : multiplex_protocol_(multiplex_protocol),
        bldc_(bldc_servo) {
    command_manager->Register(
        "d", std::bind(&Impl::HandleCommand, this,
                       std::placeholders::_1, std::placeholders::_2));

    data_update_ = telemetry_manager->Register("board_debug", &data_);
  }

  void PollMillisecond() {
    if (motor_cal_mode_ != kNoMotorCal) {
      DoCalibration();
    }
    if (histogram_active_) {
      DoHistogram();
    }
  }

  bool ParseHistogramChannel(HistogramSource* source, const std::string_view& spec) {
    // The format of this specification is a single character source:
    //
    //  t - electrical theta
    //  c - compensated
    //  f - filtered
    //  o - offset
    //  r - raw
    //  v - pll output velocity
    //  ... etc ...
    //
    // followed by an optional single digit to specify the encoder
    // channel, and then an optional list of non-digit flags:
    //
    //  d - derivative

    source->derivative = false;
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

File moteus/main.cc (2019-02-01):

// Copyright 2018 Josh Pieper, jjp@pobox.com.
//
// Licensed under the Apache License, Version 2.0 (the "License");
// you may not use this file except in compliance with the License.
// You may obtain a copy of the License at
//
//     http://www.apache.org/licenses/LICENSE-2.0
//
// Unless required by applicable law or agreed to in writing, software
// distributed under the License is distributed on an "AS IS" BASIS,
// WITHOUT WARRANTIES OR CONDITIONS OF ANY KIND, either express or implied.
// See the License for the specific language governing permissions and
// limitations under the License.

#include <inttypes.h>

#include <functional>

#include "mbed.h"

#include "mjlib/micro/async_exclusive.h"
#include "mjlib/micro/async_stream.h"
#include "mjlib/micro/command_manager.h"
#include "mjlib/micro/multiplex_protocol.h"
#include "mjlib/micro/persistent_config.h"
#include "mjlib/micro/telemetry_manager.h"

#include "moteus/board_debug.h"
#include "moteus/hw.h"
#include "moteus/millisecond_timer.h"
#include "moteus/stm32f446_async_uart.h"
#include "moteus/stm32_flash.h"
#include "moteus/system_info.h"

using namespace moteus;
namespace micro = mjlib::micro;

int main(void) {
  DigitalIn hwrev0(HWREV_PIN0, PullUp);
  DigitalIn hwrev1(HWREV_PIN1, PullUp);
  DigitalIn hwrev2(HWREV_PIN2, PullUp);

  const uint8_t this_hw_rev =
      0x07 & (~(hwrev0.read() |
                (hwrev1.read() << 1) |
                (hwrev2.read() << 2)));
  MJ_ASSERT(this_hw_rev == MOTEUS_HW_REV);

  // I initially used a Ticker here to enqueue events at 1ms
  // intervals.  However, it introduced jitter into the current
  // sampling interrupt, and I couldn't figure out how to get the
  // interrupt priorities right.  Thus for now we just poll to look
  // for millisecond turnover.
  MillisecondTimer timer;

  micro::SizedPool<12288> pool;

  Stm32F446AsyncUart rs485(&pool, &timer, []() {
      Stm32F446AsyncUart::Options options;
      options.tx = PA_9;
      options.rx = PA_10;
      options.dir = PA_8;
      options.enable_delay_us = 1;
      options.disable_delay_us = 2;
      options.baud_rate = 3000000;
      return options;
    }());

  micro::MultiplexProtocolServer multiplex_protocol(&pool, &rs485, nullptr, {});

  micro::AsyncStream* serial = multiplex_protocol.MakeTunnel(1);

  micro::AsyncExclusive<micro::AsyncWriteStream> write_stream(serial);
  micro::CommandManager command_manager(&pool, serial, &write_stream);
  micro::TelemetryManager telemetry_manager(
      &pool, &command_manager, &write_stream);
  Stm32Flash flash_interface;
  micro::PersistentConfig persistent_config(pool, command_manager, flash_interface);

  SystemInfo system_info(pool, telemetry_manager);

  BoardDebug board_debug(&pool, &persistent_config, &command_manager, &telemetry_manager, &timer);

  persistent_config.Register("id", multiplex_protocol.config(), [](){});

  persistent_config.Load();

  board_debug.Start();
  command_manager.AsyncStart();
  multiplex_protocol.Start();

  auto old_time = timer.read_ms();

  for (;;) {
    rs485.Poll();

    const auto new_time = timer.read_ms();

    if (new_time != old_time) {
      telemetry_manager.PollMillisecond();
      system_info.PollMillisecond();
      board_debug.PollMillisecond();

      old_time = new_time;
    }
    SystemInfo::idle_count++;
  }

  return 0;
}

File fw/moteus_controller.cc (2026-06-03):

// Copyright 2023 mjbots Robotic Systems, LLC.  info@mjbots.com
//
// Licensed under the Apache License, Version 2.0 (the "License");
// you may not use this file except in compliance with the License.
// You may obtain a copy of the License at
//
//     http://www.apache.org/licenses/LICENSE-2.0
//
// Unless required by applicable law or agreed to in writing, software
// distributed under the License is distributed on an "AS IS" BASIS,
// WITHOUT WARRANTIES OR CONDITIONS OF ANY KIND, either express or implied.
// See the License for the specific language governing permissions and
// limitations under the License.

#include "fw/moteus_controller.h"

#include "mjlib/base/limit.h"

#include "fw/aux_port.h"
#include "fw/drv8323.h"
#include "fw/math.h"
#include "fw/moteus_hw.h"
#include "fw/motor_position.h"
#include "fw/multi_transport_datagram_server.h"
#include "fw/uart_fdcanusb_micro_server.h"

namespace micro = mjlib::micro;
namespace multiplex = mjlib::multiplex;
using mjlib::base::Limit;

namespace moteus {

using Value = multiplex::MicroServer::Value;

namespace {

// Version 3: The enumerated values for the control mode changed
// meaning and voltage scale changed.
//
// Version 4: The scaling factors associated with velocity and
// position changed.
//
// Version 5: The "rezero state" was renamed to "home state" and the
// enumeration has new meaning.

constexpr int kRegisterMapVersion = 5;

template <typename T>
Value IntMapping(T value, size_t type) {
  switch (type) {
    case 0: return static_cast<int8_t>(value);
    case 1: return static_cast<int16_t>(value);
    case 2: return static_cast<int32_t>(value);
    case 3: return static_cast<float>(value);
  }
  MJ_ASSERT(false);
  return static_cast<int8_t>(0);
}

template <typename T>
Value ScaleSaturate(float value, float scale) {
  if (!std::isfinite(value)) {
    return std::numeric_limits<T>::min();
  }

  const float scaled = value / scale;
  const auto max = std::numeric_limits<T>::max();
  const auto float_max = static_cast<float>(max);

  // We purposefully limit to +- max, rather than to min.  The minimum
  // value for our two's complement types is reserved for NaN.
  return static_cast<T>(Limit<float>(scaled, -float_max, float_max));
}

Value ScaleMapping(float value,
                   float int8_scale, float int16_scale, float int32_scale,
                   size_t type) {
  switch (type) {
    case 0: return ScaleSaturate<int8_t>(value, int8_scale);
    case 1: return ScaleSaturate<int16_t>(value, int16_scale);
    case 2: return ScaleSaturate<int32_t>(value, int32_scale);
    case 3: return Value(value);
  }
  MJ_ASSERT(false);
  return Value(static_cast<int8_t>(0));
}

Value ScalePosition(float value, size_t type) {
  return ScaleMapping(value, 0.01f, 0.0001f, 0.00001f, type);
}

Value ScaleVelocity(float value, size_t type) {
  return ScaleMapping(value, 0.1f, 0.00025f, 0.00001f, type);
}

Value ScaleAcceleration(float value, size_t type) {
  return ScaleMapping(value, 0.05f, 0.001f, 0.00001f, type);
}

Value ScaleTemperature(float value, size_t type) {
  return ScaleMapping(value, 1.0f, 0.1f, 0.001f, type);
}

Value ScalePwm(float value, size_t type) {
  return ScaleMapping(value, 1.0f / 127.0f, 1.0f / 32767.0f,
                      1.0f / 2147483647.0f,
                      type);
}

Value ScaleCurrent(float value, size_t type) {
  // For now, current and temperature have identical scaling.
  return ScaleTemperature(value, type);
}

Value ScaleVoltage(float value, size_t type) {
  return ScaleMapping(value, 0.5f, 0.1f, 0.001f, type);
}

Value ScaleTorque(float value, size_t type) {
  return ScaleMapping(value, 0.5f, 0.01f, 0.001f, type);
}

Value ScaleTime(float value, size_t type) {
  return ScaleMapping(value, 0.01f, 0.001f, 0.000001f, type);
}

Value ScalePower(float value, size_t type) {
  return ScaleMapping(value, 10.0f, 0.05f, 0.0001f, type);
}

int8_t ReadIntMapping(Value value) {
  return std::visit([](auto a) {
    return static_cast<int8_t>(a);
  }, value);
}

int32_t ReadInt32Mapping(Value value) {
  return std::visit([](auto a) {
    return static_cast<int32_t>(a);
  }, value);
}

struct ValueScaler {
  float int8_scale;
  float int16_scale;
  float int32_scale;

  float operator()(int8_t value) const {
    if (value == std::numeric_limits<int8_t>::min()) {
      return std::numeric_limits<float>::quiet_NaN();
    }
    return value * int8_scale;
  }

  float operator()(int16_t value) const {
    if (value == std::numeric_limits<int16_t>::min()) {
      return std::numeric_limits<float>::quiet_NaN();
    }
    return value * int16_scale;
  }

  float operator()(int32_t value) const {
    if (value == std::numeric_limits<int32_t>::min()) {
      return std::numeric_limits<float>::quiet_NaN();
    }
    return value * int32_scale;
  }

  float operator()(float value) const {
    return value;
  }
};

float ReadScaleMapping(Value value,
                       float int8_scale,
                       float int16_scale,
                       float int32_scale) {
  return std::visit(ValueScaler{int8_scale, int16_scale, int32_scale}, value);
}

float ReadPwm(Value value) {
  return ReadScaleMapping(value, 1.0f / 127.0f, 1.0f / 32767.0f,
                          1.0f / 2147483647.0f);
}

float ReadVoltage(Value value) {
  return ReadScaleMapping(value, 0.5f, 0.1f, 0.001f);
}

float ReadPosition(Value value) {
  return ReadScaleMapping(value, 0.01f, 0.0001f, 0.00001f);
}

float ReadVelocity(Value value) {
  return ReadScaleMapping(value, 0.1f, 0.00025f, 0.00001f);
}

float ReadAcceleration(Value value) {
  return ReadScaleMapping(value, 0.05f, 0.001f, 0.00001f);
}

float ReadCurrent(Value value) {
  return ReadScaleMapping(value, 1.0f, 0.1f, 0.001f);
}

float ReadTorque(Value value) {
  return ReadScaleMapping(value, 0.5f, 0.01f, 0.001f);
}

float ReadTime(Value value) {
  return ReadScaleMapping(value, 0.01f, 0.001f, 0.000001f);
}

template <typename T, size_t N>
int8_t PinsToBits(const std::array<T, N>& array) {
  static_assert(N <= 7);
  int8_t result = 0;
  for (size_t i = 0; i < array.size(); i++) {
    result |= (array[i] ? 1 : 0) << i;
  }
  return result;
}
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

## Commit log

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2021-01-13 Fix the sign of the feedforward velocity component
    This requires some moderately extensive backward compatibility changes
    so that old hardware which has a new firmware applied won't result in
    an inherently unstable system.
    [bldc_servo.cc]
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2021-02-13 Verify slip is compatible with position bounds
    When max_position_slip is enabled, you shouldn't be able to drag the
    controller so that the controlled position is outside the configured
    position bounds.
    [dynamometer_drive.cc, firmware_validate.py]
2021-02-13 Make control_position wrap in a controlled location
    This ensures that slip calculations work correctly across wraparound,
    and is generally a good thing to do.
    [bldc_servo.cc, dynamometer_drive.cc]
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2021-03-09 Limit the DQ integrator to an achievable voltage
    Previously, the DQ integrator would be allowed to wind up well beyond
    the maximum voltage that could be output. If operating at the maximum
    possible speed, this could result in large delays when slowing down.
    We also tweak the test fixture's rigid PID parameters to work with
    modern firmwares.
    [bldc_servo.cc, dynamometer_drive.cc, firmware_validate.py]
2021-03-09 Limit the maximum power in firmware
    This is just a configurable parameter, but should make the default
    configuration less likely to explode and gives users a way to further
    limit the power for certain applications.
    Note, power limiting won't necessarily play well with higher level
    control loops if integrators are involved, as they will just wind up.
    [bldc_servo.cc, dynamometer_drive.cc, firmware_validate.py]
2021-03-09 Implement a maximum velocity limit
    When the measured velocity exceeds this value, the allowable output
    current is derated, reaching 0 at the top of the derating window.
    The default maximum is large, 30000rpm, which is beyond what the
    system can support. The devkit default maximum is 600rpm, so as to
    make using the devkit less error prone out of the box.
    [20200122-beta-devkit-6008.cfg]
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2021-04-09 Support AS5048B encoders on the auxiliary port
    The following functions are supported:
    * Offsetting and scaling the value
    * Reading from the diagnostic and register interface
    * Python binding support
    * Initializing "unwrapped_position" at startup
    [bldc_servo.cc, dynamometer_drive.cc, moteus_controller.cc]
2021-04-13 Revise the controller to r4.5b
    * The primary difference is that this uses the easier to acquire
    DRV8535 gate driver chip, instead of the previous DRV8323. Because
    of the details of that product line, we now have a separate DC/DC
    regulator as the built-in regulator variant of the DRV8535 line
    doesn't suit the moteus's needs as well
    * The primary encoder SPI lines are broken out to an optional
    PICO-SPOX connector, so that external encoders could be supported
    * There are now optional back-side capacitors for increased DC link
    capacitance
    * The logic routing has been completely redone by hand
    * Power level signal spacing is larger, and all logic level spacing is
    at roughly 6mil sp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
    [controller.brd, controller.sch]
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2021-04-20 Switch unwrapped_position_raw to be 64 bits
    This is now in the same units as control_position. This is to
    eventually support encoder filtering, for which more resolution will
    be desired.
    We also update mjlib to get better error messages.
    [bldc_servo.cc, dynamometer_drive.cc]
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2021-04-24 Only limit for maximum velocity if we're accelerating
    Exceeding the maximum velocity is documented as resulting in "odd
    behavior", but without this, it could easily oscillate by large
    amounts.
    [bldc_servo.cc]
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2021-04-25 Better support for selecting direction of motor rotation
    * Add a new motor config parameter, 'motor.phase_invert', which in
    software swaps phase B and C PWM and current sense. This goes along
    with the existing 'motor.invert' (now somewhat poorly named) which
    inverts the sense of the encoder.
    * During calibration moteus_tool now attempts to configure the motor
    so that positive commands result in the encoder moving in a positive
    direction. `--cal-invert` does the opposite, and has positive
    commands result in the encoder moving negative. If a particular
    direction would require 'motor.phase_invert' support, and the
    firmware does not support it, then fail.
    This means that whe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
    [bldc_servo.cc]
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2021-05-04 Use the correct ratio when limiting the current integrator
    This is a followup to d61fd21e96fb2d33bc887d34d8f3ef57bf9f206d, where
    we incorrectly limited ourselves to half of the maximum speed.
    [bldc_servo.cc]
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2021-06-09 Make rezeroing to non-zero positions work again
    This was broken in 5e3d7f1997dc33627ff8876908c39a6f24705926
    [bldc_servo.cc, dynamometer_drive.cc, firmware_validate.py]
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2021-06-16 Improve error handling in the bootloader
    * Consistently use the 'ERR' prefix before error messages
    * If the hardware complains, report the error bits in the error message
    [can_bootloader.cc]
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2021-08-20 Slight tweaks to dyno constants to handle a fixture with newer firmware
    [dynamometer_drive.cc]
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2021-09-09 Beginnings of r4.6 * Fix grounding around MAX15062AATA+T * Add a TVS diode on the CAN lines * Add test pads for the current sense line, move logo down slightly to make room * Remove paste from pico-s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
    [controller.brd, controller.sch]
2021-09-09 More progress on r4.6
    * Redid layout for 3.3V regulator
    * Fixed silk labels for secondary encoder connector
    * Switched 3.3V regulator inductor to the 33uH "semi-shielded" family
    from r4.5
    [controller.brd, controller.sch]
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2021-09-21 Make r4.8 boards better match r4.5 in voltage mode
    This primarily affects the results of Kv and winding resistance
    calculations, but also makes slightly less audible noise when
    controlling for zero current and slightly more nonlinearity around 0
    current.
    [bldc_servo.cc]
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2021-12-03 Initial version of a "fixed voltage mode"
    In this mode, the encoder and current sense resistors are not used at
    all for control. Instead, a fixed voltage is applied to the motor at
    all times, and the phase of that voltage is controlled by the
    commanded motion profile.
    [bldc_servo.cc]
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2022-03-10 Remove PWM compensation when using current mode control
    It isn't necessary and uses more cycles. It increases the noise on
    the PWM lines, which could theoretically result in increased audible
    noise.
    In practice, it doesn't seem to change anything though aside from
    saving some cycles in the long path.
    Some tests had to be tweaked. Notably power limits at very low levels
    will now give slightly different and less accurate results.
    [bldc_servo.cc, dynamometer_drive.cc]
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2022-03-12 Implement a "brake" mode
    This can be used to short the motor phases together, resulting in a
    passive braking action.
    [bldc_servo.cc, board_debug.cc, dynamometer_drive.cc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]
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2022-04-07 Implement velocity and acceleration limited trajectories
    With this feature, the major position mode commands still have the
    same inputs, but when either velocity or acceleration limits are
    engaged, their semantics change significantly.
    Previously, if a command like "d pos 3 0 0.5" were issue, the
    controller would instantaneously attempt to achieve position 3. Now,
    if instead "d pos 3 0 0.5 v1 a2" is issued, the controller will
    gradually accelerate at 2rev/s^2, max out at a velocity of 1rev/s, and
    then decelerate at 2rev/s^2 to come to a gentle stop at position 3.
    The limits can be configured globally, or overidden on a per-command
    basis in the same manner as the watchdog timeout or maximu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
    [bldc_servo.cc, bldc_servo_position.h, bldc_servo_structs.h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]
2022-04-07 Keep around a 10ms filtered velocity, use it for capturing
    Errors in the initial captured velocity can be greatly magnified when
    the acceleration limited trajectory planner is involved. So in
    addition to using the filtered velocity, we also clamp it hard to 0.0
    if under a configurable value.
    [bldc_servo.cc, bldc_servo_position.h, bldc_servo_structs.h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]
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2022-04-30 moteus r4.10
    * Fixed version pins to actually be the next one after r4.8
    * Just made a silk outline on the heatsink area, rather than hatched
    * Added 0 ohm gate drive resistors
    * Add low side gate clamping diodes
    * Minor trace position tweaks for improved clearance
    * Add gate drive diodes to enable strong pull-down even if the gate
    drive resistors are non-zero
    * center the status LEDs
    [controller.brd, controller.sch]
2022-04-30 moteus r4.11 * Remove snubbers * Switch gate drive resistors to 7.5 ohm * Turn off paste on the SOT23-8 TCAN footprint * Fix MPNs for the TCAN parts
    [controller.brd, controller.sch]
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2022-05-03 Attempt to recover from busoff events
    The controller can go busoff as a result of signal integrity problems
    on the CAN line. Attempt to recover, and report over the diagnostic
    protocol the number of times a reset was required.
    [fdcan.cc, fdcan.h]
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2022-05-09 Revert "Remove PWM compensation when using current mode control"
    This reverts commit 02d549ee2a3f888d2088c124d395da8095c1dfbd.
    r4.8 boards (which have more exaggerated PWM compensation constants),
    still benefit from this a lot.
    Tweak the dyno cycle limit to pass.
    [bldc_servo.cc, dynamometer_drive.cc]
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2022-06-23 Fixes for quadrature operation * Use a 32 bit count so we can have more than 64k counts per revolution * Properly apply the sign
    [aux_common.h, motor_position.h]
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2022-07-08 Make motor_position.output.sign actually work
    This was never tested, and apparently didn't really do anything. Unit
    test its behavior, and verify by manual testing that changing
    output.sign does change the direction of motion with no other changes
    required.
    Note that output.offset and output.sign have the same less than
    desirable interaction that source.offset and source.sign do, but at
    least it is consistent.
    Resolves #33
    [bldc_servo.cc, motor_position.h]
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2022-07-25 Add back in a bemf feedforward term
    Unlike the last incarnation, this one is based on commanded velocity,
    so it is not sensitive to feedback issues
    [bldc_servo.cc, bldc_servo_structs.h]
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2022-07-28 Revert a60aab46018a456df7f3ab6c5661711e0e00878c
    I'm not sure what I was testing with, but all 5 motors I have tested
    with today limit to half of the power specified with this change.
    [bldc_servo.cc, dynamometer_drive.cc]
2022-07-30 Initialize the STM32G4 ADCs in turn, rather than all at once
    The datasheet says nothing about simultaneous initialization being
    problematic. However, if the ADEN bits of two ADCs are turned on in
    too close proximity to each other, "bad things" happen. Here, the
    observed failure was that the prescaler seemed to be set back to 1,
    despite the prescaler register still reading the non-unity value set.
    This probably only started being a problem with the switch to gcc-11,
    which did a better job of packing these enables into a smaller amount
    of time. Even so, it would only be triggered when the code aligned
    properly onto some boundary, probably the flash accelerator fetch
    block. Thus the proble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
    [bldc_servo.cc]
2022-07-30 Increase the ADC prescale from 6 to 8
    Now that I know how to more accurately diagnose prescale issues,
    moteus was still having slight distortion around the 0 current point
    because of the prescaler. Now that 30kHz is our max control rate, we
    have sufficient time left to increase this and get that fidelity back.
    [bldc_servo.cc, dynamometer_drive.cc]
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2022-08-30 Use bemf_feedforward when in fixed_voltage_mode
    If the motor.v_per_hz is configured correctly, this should allow
    gimbal control mode to operate at any speed. It also allows AC
    induction motors to be operated in an open loop V/Hz control mode
    using the same mode, but with config_.fixed_voltage_control_V=0.
    [bldc_servo.cc]
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2023-01-26 Report control position, velocity, and torque along with errors
    The current trajectory control position, velocity, and torque are now
    exposed in a uniform manner over the register protocol. Additionally,
    control position is now available via the diagnostic protocol in float
    form, whereas it was previously only visible in relative int64 counts.
    Add a simple python example which queries all of those values while
    commanding an oscillating trajectory.
    [bldc_servo.cc, bldc_servo_position.h, bldc_servo_structs.h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]
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2023-01-27 Actually, the current PLL filter bandwidth is unstable at more than 1/10th
    [motor_position.h]
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2023-02-25 moteus n1 r1.1
    * Set DRC to MF 2oz rules
    * ripup everything
    * switch MCU pins to new assignments
    * add in second I2C pullups
    * and filter cap placeholders on all port lines
    * Add in a RS422 connector
    * Get logo and name to a reasonable-ish place
    * Update TVS diode with more precise one that is in stock
    * Fix MPN for RS422 connector
    [moteus_n1.brd, moteus_n1.sch]
2023-02-25 moteus n1 r1.2
    * Bump board version to r1.2
    * Fix T and R labels
    * Move 5V test pad away from power connector
    * Move phase terminal stop 0.2mm further away from FET stop
    * In the library, remove stop mask from the in-pad vias, relying
    just on the polygon stop mask so that we don't have to worry
    about stop mask making it outside our intended region.
    * Remove silks around FETs
    * Space FETS out more
    * Move motor temp pads 1mm further away from the edge
    * Resize the logo and board name to the r4.11 size
    * Move board label back to tNames layer
    [moteus_n1.brd, moteus_n1.sch]
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2023-03-15 Make ADC initialization occur at fixed phasing relative to their prescaler
    In a398d0c4fde08ea5a585bbf0d53da6be422e0915 the initialization
    sequence was changed to improve performance. While that helped at the
    time, and I believed made the initialization robust it seems that it
    was possible for other phasing issues to cause problems. Notably, if
    ADC3 was initialized at some relative phases w.r.t. ADC1, then the
    ADC1 conversions would have undesired noise at some frequencies.
    To resolve this, we add some inline assembly that ensures that the ADC
    enable bit gets flipped at the exact same clock cycle relative to the
    prescaler every time.
    [bldc_servo.cc]
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2023-05-23 Ensure that relative position stays in sync with the encoder
    The relative position was calculated by measuring the encoder delta,
    scaling it by the gear ratio, and then accumulating. However, due to
    floating point error, this conversion is lossy, and if the encoder
    goes from reading 1 to 2, and then back to 1, the relative position
    will not necessarily end up at the exact same location.
    Instead, now, we ensure that the relative position is always equal to
    an integer number of encoder revolutions plus the current filtered
    encoder value.
    This adds roughly 5-8 cycles to the ISR.
    [dynamometer_drive.cc, motor_position.h]
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2023-06-03 Significantly improve ADC performance
    In 5eb9139287eeac3f02553ba0b306be6d26c25407 and previously
    a398d0c4fde08ea5a585bbf0d53da6be422e0915, work was done to identify
    ADC performance issues. In the meantime, ST released new errata for
    the STM32G474 ADC which more accurately describes problematic
    configurations when multiple ADCs are used simultaneously.
    * ES0430 - Rev 8, 2.7.9
    Notably, to achieve optimal results, the documented workaround is to
    use a synchronous clock mode with a prescaler no more than 1 (!), and
    also to trigger all ADCs simultaneously by using a hardware trigger.
    Using a prescaler of exactly 1 is hard for moteus, since that would
    run the ADC too fast, at 85Mhz. Instead,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
    [bldc_servo.cc, bldc_servo_structs.h]
2023-06-05 Updates to HIL tests * Lock in a 50 cycle improvement in ISR timing * Record `motor_position` along with other telemetry * When testing PWM mode, execute a short sweep to lock in position, otherwise 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
    [dynamometer_drive.cc, firmware_validate.py]
2023-06-14 Be more robust to startup ordering
    In some cases, it was reported that when attempting to enable the
    driver immediately after powering on, this assert could trigger. I
    believe with the DRV8353 (but probably not the DRV8323), the
    calibration sequence is automatically initiated on startup and can be
    reported as being active over SPI.
    So for now, just don't even care what it was to begin with, and ensure
    that we set all the regs to 0 before leaving. Add a new fault code
    for if that somehow goes wrong.
    [bldc_servo.cc, drv8323.cc, drv8323.h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]
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2023-06-21 Fix motor_position.output.sign == -1
    Commit a3fddce7e2e1c5cf09abb08835f086e426a3c04c complete broke
    positioning with sign==-1, however it managed to squeak through all of
    the tests for that configuration. Fix it, and make both some unit
    tests and system tests to try and catch similar problems in the
    future.
    [dynamometer_drive.cc, firmware_validate.py, motor_position.h]
2023-07-13 moteus-n1 r1.3 * Update the version check divider * set 5V regulator to PWM mode * switch 3V regulator to ADP5301 - the old one had no way to configure fixed frequency switching, which we want for re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
    [moteus_n1.brd, moteus_n1.sch]
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2023-07-23 Fixes for motor_position reference sources
    Reference sources were previously basically broken if an output offset
    or sign was configured. They should now be good.
    Even without a reference, if an output offset was configured, it was
    possible to start outside of +- 0.5*rotor_to_output ratio.
    [motor_position.h]
2023-07-23 Make configuring the output offset ignore the existing offset
    When offsets were broken before, this was a worse problem, but there
    is still no good reason to start from whatever random offset we had
    previously, as it can allow the offset to drift arbitrarily many
    cycles away from 0.0.
    [board_debug.cc]
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2023-07-23 Update the moteus-n1 5V regulator "value" to be MAX15062BATA+T
    The MPN attribute was always correct and is canonical, but this makes
    confusion less likely.
    [moteus_n1.brd, moteus_n1.sch]
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2023-07-24 Ensure everything is stopped when entering the bootloader
    While we're at it, ensure the primary ISR is stopped when entering the
    bootloader or when an assertion failure occurs.
    [board_debug.cc]
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2023-09-18 Make the controller fault if a stop position is used with limits
    The semantics of combining stop position with limits are basically
    useless, and many people erroneously think they have problems when in
    fact they just didn't realize that there isn't much use for stop
    positions anymore. Now we fault in that case, which will hopefully
    alert users much more quickly that they either should stop using "stop
    position", or conversely, should disable all their position and
    velocity limits.
    [bldc_servo.cc, error.h]
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2023-10-20 Ignore user commands when in position timeout mode with zero velocity configured
    This was always the intended behavior, but became broken with the
    addition of acceleration and velocity limited trajectories.
    [bldc_servo.cc]
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2023-11-17 Limit our encoder velocity to one which is usefully measurable
    Previously, if the velocity became too high, it could PLL onto an
    integral multiple of the measurable rate, resulting in non-physical
    velocities and positions.
    [dynamometer_drive.cc, motor_position.h]
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2023-12-04 Tweak in-family results and ensure that main loop stalls will result in faults
    [dynamometer_drive.cc]
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2024-05-10 Make board_debug commands error on malformed values
    A common mistake has been to send a command like:
    d pos 0 0 f1
    Which previously would be erroneously accepted. The "f1" would be
    accepted as a maximum torque, parsed as 0, and no feedforward torque
    would be applied at all. Now we error for all floating point parsing
    that is malformed.
    [board_debug.cc]
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2024-05-20 Finally get power limit and reported power scaled correctly
    Went back to the source, and sure enough there is a 3/2 factor when
    converting between phase current and voltage and overall system power.
    [bldc_servo.cc]
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2024-06-07 Restrict how the bemf feedforward term can be used
    * Default it to off, as it isn't necessary in most applications and
    presumes that commanded trajectories are always physically
    achievable
    * If it is configured, fault if the most common reason for
    non-physically achievable trajectories is configured, i.e. no
    acceleration limit.
    * Upgrade and downgrade this across firmware version flashes
    While we are at it, make moteus_tool fail when trying to downgrade a
    board which has too new of a firmware version, which we have not done
    to date but is necessary to maintain downgrade semantics.
    [bldc_servo.cc, bldc_servo_structs.h, error.h]
2024-06-07 By default, fault if a non-reducing gear ratio is configured
    This is expected to be extremely rare to be used correctly. When used
    incorrectly though, since PID gains are measured at the output, this
    can result in drastic and undamped current outputs when control is
    attempted. This should hopefully reduce the odds someone breaks their
    system this particular way.
    [motor_position.h]
2024-06-07 Limit the maximum commanded velocity to something achievable
    Commanding non-physically achievable velocities can cause many
    problems, among them:
    * Windup if an acceleration limit is configured
    * If bemf feedforward is configured, it allows commands to cause
    arbitrary current output, completely ignoring any configured current
    limits
    [bldc_servo.cc, bldc_servo_position.h, bldc_servo_structs.h]
2024-06-07 Timeout encoders that are no longer active
    Mark the aksim2 as not active if it reports an error
    [motor_position.h]
2024-06-17 Fix an accidental default testing mode that blocked the final two tests
    [dynamometer_drive.cc]
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2024-06-27 Interpolate commutation theta offsets
    Older versions of moteus_tool can generate offset tables which are not
    suitable for interpolation. Try to catch those and error so the user
    knows they need to re-calibrate.
    This almost certainly puts our ISR execution time above the dyno test
    limits. Later work will have to optimize the performance of this.
    [motor_position.h]
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2024-11-11 Reference compensation improvements
    * Add a configurable skip time when recording data
    * Imply --absolute, as there is no need to use incremental if we have
    a reference
    [compensate_encoder.py]
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2025-03-12 Improve inductance calibration for all motor types
    Measure inductance with a voltage square wave that is not centered
    around 0V. There is a large non-linearity around 0 current. By
    offsetting our inductance calibration waveform, we get a much more
    accurate result.
    To accomplish this, "d ind" now accepts an optional fixed voltage
    override and an optional method to ignore bounds (although it is not
    required yet).
    [bldc_servo.cc, board_debug.cc]
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

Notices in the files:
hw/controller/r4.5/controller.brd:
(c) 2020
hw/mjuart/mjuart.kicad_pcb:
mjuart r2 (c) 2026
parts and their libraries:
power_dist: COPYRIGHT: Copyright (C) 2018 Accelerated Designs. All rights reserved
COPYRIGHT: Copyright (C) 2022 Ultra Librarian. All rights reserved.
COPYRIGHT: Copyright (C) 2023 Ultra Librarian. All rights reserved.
